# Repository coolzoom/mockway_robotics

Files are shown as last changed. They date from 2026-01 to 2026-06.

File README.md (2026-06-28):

<div align="center">
  

  # 牧卫机器人

  开源六轴协作机械臂系统，包含机械结构、电路和软件

</div>

**中文 | [English](README_EN.md)**

robotarm_base (https://www.bilibili.com/video/BV1AxrbBWEjN/)

> 视频中测试程序为`tools/dynamics_test/real/inverse_dynamics_test.py`脚本
> 
> 运行后选择：1-重力补偿模式
> 
> 根据实际情况配置`tools/dynamics_test/dynamics_test.yaml`中串口等信息

CAN设备使用[维特USB-CAN模块](https://detail.tmall.com/item.htm?id=598670674373&skuId=4483773298672)，串口波特率921600，CAN总线波特率1M

## ⚙️ 机械结构

使用`JellyCAD`参数化建模，模型参数在`/jellycad_src`目录下，软件下载地址：[JellyCAD v0.3.10](https://github.com/Jelatine/JellyCAD/releases/tag/v0.3.10)

结构件可3D打印，已上传到[MakerWorld](https://makerworld.com.cn/zh/models/2037149-mockway-kai-yuan-liu-zhou-xie-zuo-ji-jie-bi#profileId-2273199)

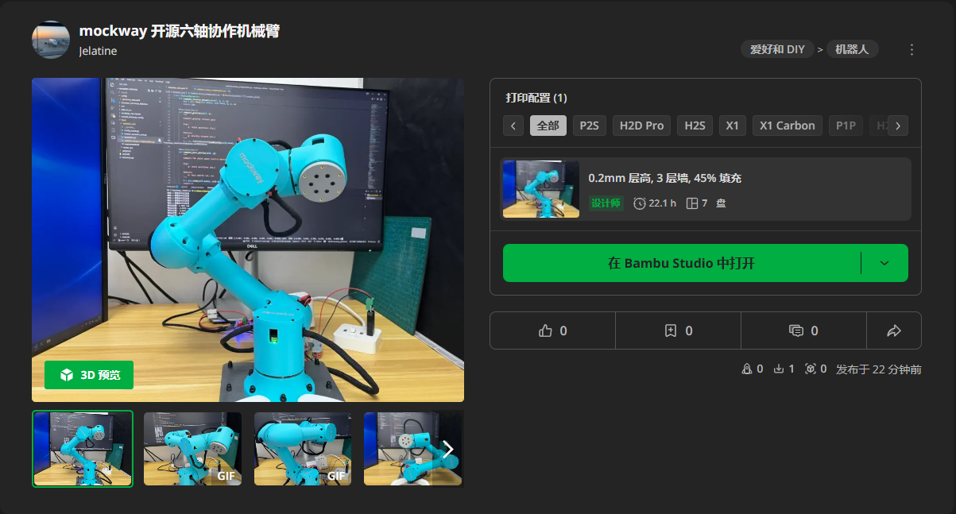
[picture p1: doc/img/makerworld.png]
makerworld (https://makerworld.com.cn/zh/models/2037149-mockway-kai-yuan-liu-zhou-xie-zuo-ji-jie-bi#profileId-2273199)


[组装指南.md](doc/组装指南.md)

## 🚀 程序运行

### 🎮 电机调试

单个电机运动调试和关节零点标定的界面

```bash
python tools/motor_gui/motor_gui.py
```

motor_gui

### ⚡ 力矩补偿

```bash
python tools/dynamics_test/realtime_torque_compensation.py
```

torque_compensation

> 运行前请阅读下面 `⚠️ 注意事项`

### 🦾 运行MoveIt!

建议运行环境：

- Ubuntu 24.04
- ROS2 Jazzy + MoveIt!

1. 创建工作空间

```bash
mkdir -p ~/mockway_ws/src
cd ~/mockway_ws/src
```

2. 克隆mockway_robotics仓库

```bash
git clone https://github.com/Jelatine/mockway_robotics.git
```

3. 编译工作空间

```bash
cd ~/mockway_ws
rosdep install --from-paths src/mockway_robotics/moveit_mockway_config/ --ignore-src -r -y
colcon build --symlink-install --packages-select moveit_mockway_config
```
4. 配置环境变量

```bash
source ~/mockway_ws/install/setup.bash
```

5. 启动程序（默认真机，需 USB-CAN 与 24V 供电）

```bash
# WSL 先透传 USB: tools\setup_wsl_moveit.bat 6
ros2 launch moveit_mockway_config demo.launch.py
# 无硬件仿真:
ros2 launch moveit_mockway_config demo.launch.py use_mock_hardware:=true
```

moveit_demo

**MoveIt 启动卡住？** 若终端反复出现 `Failed to acquire lock in 20 seconds`（`spawner_mockway_group_controller`），且 RViz 一直停在启动界面，多半是 **电机 CAN 连线或供电问题**（接线松动、CAN_H/L 接反、未上 24V、ID 冲突等）。请先逐台检查电机与 USB-CAN 模块，用 `motor_gui` 确认各关节能单独通信；仅做界面仿真时可加 `use_mock_hardware:=true` 排除软件问题。详见 [组装指南 · 故障排查](doc/组装指南.html#troubleshoot)。

### 🖥️ 完整程序

1. 安装`lua`

```bash
sudo apt install liblua5.4-dev
```

2. 构建`mockway_bringup`

```bash
cd ~/mockway_ws
rosdep install --from-paths src/mockway_robotics/ --ignore-src -r -y
colcon build --symlink-install --packages-select mockway_bringup
```
3. 启动程序

```bash
# 启动 move_group + servo ,仿真：use_mock_hardware:=true
ros2 launch mockway_bringup bringup.launch.py use_mock_hardware:=true
# 浏览器打开前端：http://localhost:8080/
```

### 🦞 OpenClaw应用

[应用视频](https://www.bilibili.com/video/BV1hnAjz9ESU/)

1. 将[skill](mockway_lua_moveit\robot_skill.md)文件放到openclaw的workspace目录下
2. 对话时让大模型学习skill文件中的指令，以及机械臂控制器的IP地址(或主机名)
3. 用自然语言控制机械臂，如：直线向上移动10厘米

## 📦 物料清单

详细的物料清单请查看：[BOM.md](doc/BOM.md)

复刻成本约4.2k（电机≈4k，打印件≈20，USB2CAN≈73，电源≈100，螺丝及工具<40）

## 🔌 电气连接

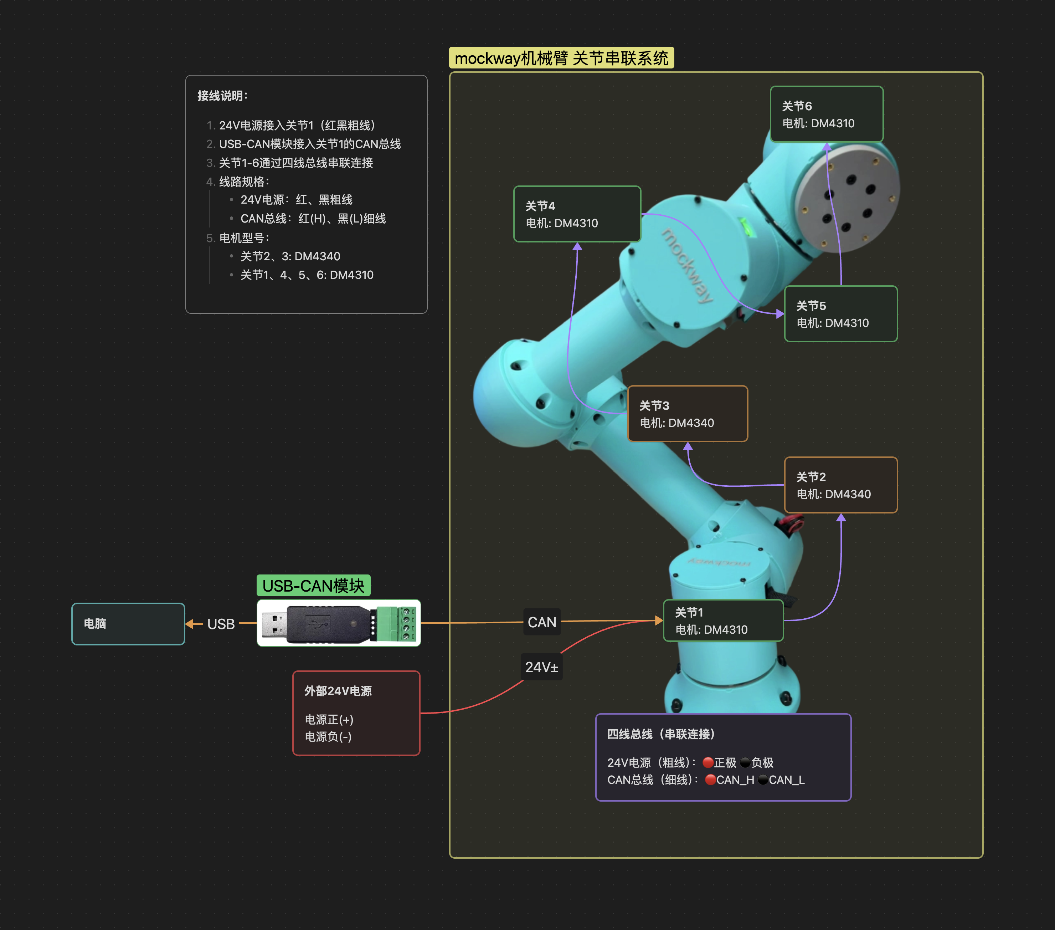
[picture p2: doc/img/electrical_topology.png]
electrical_topology


## ⚠️ 注意事项

**重要提示：力矩模式如果前期准备没做好容易发生飞车（失控）现象，请务必按照以下步骤操作。**

### 1. 结构匹配

确保机械结构与URDF模型一致。GitHub仓库最新版本已包含所有必需的结构件。

### 2. 关节零点标定

使用电机调试界面标定各关节零点位置，零点姿态需参考URDF定义。

```bash
python tools/motor_gui/motor_gui.py
```

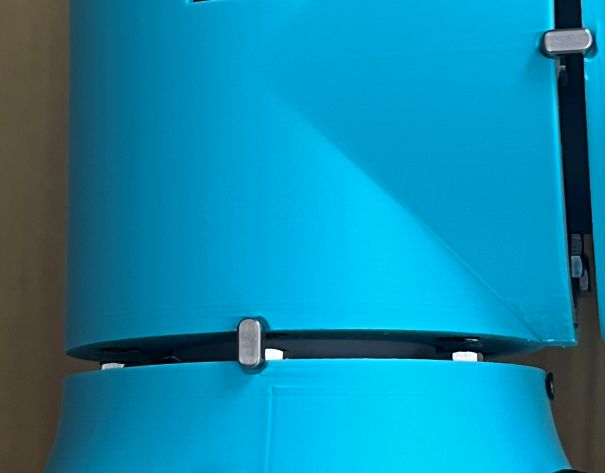
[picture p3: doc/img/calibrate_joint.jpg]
calibrate_joint


### 3. 力矩值验证

在代码中注释掉`controller.enable_motors()`，先运行程序观察计算的力矩值是否正常。有条件的话，建议先运行一次位置模式，对比实际力矩与算法计算力矩的差异是否较小。

### 4. 重力补偿测试

初次测试时：
- 使用模式1（重力补偿模式）进行测试
- 增加电机阻尼参数：设置`mit_params.kd = 1`

### 5. 结构件打印

3D打印结构件时注意：
- 提高填充百分比（建议≥40%）
- 使用螺旋体（Gyroid）填充图案，以提高强度和减轻重量

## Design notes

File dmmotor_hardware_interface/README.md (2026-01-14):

# DM Motor Hardware Interface for ROS2 Control

ROS2 Control hardware interface plugin for DM motors (DM-J4310-2EC and DM4340) using SocketCAN.

## Features

- Support for DM-J4310-2EC and DM4340 motors
- MIT control mode for smooth position/velocity control
- SocketCAN interface for CAN communication
- Real-time motor state feedback (position, velocity, torque, temperature)
- Configurable per-joint motor parameters

## Motor Configuration

### Joint Assignment
- Joint 1 (J1): DM-J4310-2EC
- Joint 2 (J2): DM4340
- Joint 3 (J3): DM4340
- Joint 4 (J4): DM-J4310-2EC
- Joint 5 (J5): DM-J4310-2EC
- Joint 6 (J6): DM-J4310-2EC

### Motor Parameters

**DM-J4310-2EC:**
- Max Position: ±12.5 rad
- Max Velocity: 30.0 rad/s
- Max Torque: 10.0 Nm

**DM4340:**
- Max Position: ±12.5 rad
- Max Velocity: 8.0 rad/s
- Max Torque: 28.0 Nm

## Prerequisites

### 1. Install SocketCAN utilities

```bash
sudo apt-get update
sudo apt-get install can-utils
```

### 2. Configure CAN Interface

Create a script to configure the CAN interface (e.g., `/etc/systemd/system/can-setup.sh`):

```bash
#!/bin/bash
# Setup CAN interface
sudo ip link set can0 type can bitrate 1000000
sudo ip link set up can0
```

Make it executable:
```bash
chmod +x /etc/systemd/system/can-setup.sh
```

To automatically setup CAN on boot, create a systemd service (`/etc/systemd/system/can-setup.service`):

```ini
[Unit]
Description=Setup CAN interface
After=network.target

[Service]
Type=oneshot
ExecStart=/etc/systemd/system/can-setup.sh
RemainAfterExit=yes

[Install]
WantedBy=multi-user.target
```

Enable the service:
```bash
sudo systemctl daemon-reload
sudo systemctl enable can-setup.service
sudo systemctl start can-setup.service
```

### 3. Verify CAN Interface

```bash
# Check if CAN interface is up
ip link show can0

# Monitor CAN traffic
candump can0

# Send test frame
cansend can0 123#DEADBEEF
```

## Building

```bash
cd ~/ws/mockway_robotics
colcon build --packages-select dmmotor_hardware_interface
source install/setup.bash
```

## Configuration

The hardware interface is configured in the URDF/xacro file (`moveit_mockway_config/config/mockway_description.ros2_control.xacro`).

### Hardware Parameters

```xml
<hardware>
    <plugin>dmmotor_hardware_interface/DMMototHardwareInterface</plugin>
    <param name="can_port">can0</param>
    <param name="can_baudrate">1000000</param>
    <param name="position_kp">40.0</param>
    <param name="position_kd">1.0</param>
</hardware>
```

### Joint Parameters

For each joint, specify:
- `motor_id`: CAN ID of the motor (1-127)
- `master_id`: CAN ID for receiving feedback (typically 0)
- `motor_type`: Either `DM_J4310_2EC` or `DM4340`

Example:
```xml
<joint name="joint1">
    <command_interface name="position"/>
    <state_interface name="position"/>
    <state_interface name="velocity"/>
    <param name="motor_id">1</param>
    <param name="master_id">0</param>
    <param name="motor_type">DM_J4310_2EC</param>
</joint>
```

## Usage

### Starting the Hardware Interface

The hardware interface is automatically loaded by ros2_control when you launch MoveIt:

```bash
ros2 launch moveit_mockway_config demo.launch.py
```

### Motor Control Modes

The hardware interface uses **MIT control mode** for position control:

```
torque = kp * (p_cmd - p_actual) + kd * (v_cmd - v_actual)
```

Control parameters (`position_kp` and `position_kd`) can be tuned in the xacro file.

### Monitoring Motor Status

```bash
# Check joint states
ros2 topic echo /joint_states

# Monitor controller status
ros2 control list_controllers

# View hardware component status
ros2 control list_hardware_components
```

## Troubleshooting

### CAN Interface Issues

**Problem:** `Failed to open CAN interface can0`

**Solutions:**
1. Check if CAN interface exists: `ip link show can0`
2. Bring up the interface: `sudo ip link set up can0`
3. Verify bitrate: `ip -details link show can0`
4. Check permissions: Add user to `dialout` group if needed

**Problem:** `No feedback from motors`

**Solutions:**
1. Check CAN wiring and termination resistors (120Ω at both ends)
2. Verify motor power supply
3. Monitor CAN bus: `candump can0`
4. Check motor IDs match configuration
5. Ensure motors are properly enabled

**Problem:** `Motors not responding to commands`

**Solutions:**
1. Verify motors are enabled (check error codes)
2. Check motor ID configuration
3. Ensure CAN baudrate matches (1 Mbps)
4. Verify MIT control parameters are reasonable

### Error Codes

Motor error codes are reported in feedback:
- `0x0`: Disabled
- `0x1`: Enabled (normal operation)
- `0x8`: Over-voltage
- `0x9`: Under-voltage
- `0xA`: Over-current
- `0xB`: MOS over-temperature
- `0xC`: Coil over-temperature
- `0xD`: Communication loss
- `0xE`: Overload

## Safety Notes

1. **Emergency Stop**: Always have an emergency stop mechanism
2. **Workspace Limits**: Ensure joint limits are properly configured
3. **Temperature Monitoring**: Monitor motor temperatures during operation
4. **Power Supply**: Use appropriate power supply (check motor specifications)
5. **Initial Testing**: Test with low velocities and accelerations initially

## Development and Debugging

### Enable Debug Logging

```bash
ros2 launch moveit_mockway_config demo.launch.py --ros-args --log-level dmmotor_hardware_interface:=debug
```

### Test Individual Motors

Use the Python driver for testing:

```bash
cd ~/ws/mockway_robotics/tools/motor_gui
python3 dm_motor_driver.py
```

## References

- [ROS2 Control Documentation](https://control.ros.org/)
- [SocketCAN Documentation](https://www.kernel.org/doc/Documentation/networking/can.txt)
- DM Motor Manual (refer to manufacturer documentation)

## License

MIT License - Copyright (c) 2025 Mockway Robotics

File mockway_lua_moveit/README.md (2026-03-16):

# mockway_lua_moveit

使用 [sol2](https://github.com/ThePhD/sol2) 将 MoveIt 和 MoveIt Servo 封装为 Lua 全局函数，通过执行 Lua 脚本控制机械臂。

## 单位约定

> 所有 Lua API 输入/输出统一使用以下单位：
>
> | 量 | 单位 |
> |---|---|
> | 位置（x, y, z） | **mm**（毫米） |
> | 角度（关节、RPY、旋转增量） | **deg**（度） |
> | 线速度（Servo） | **mm/s** |
> | 角速度（Servo） | **deg/s** |
> | 暂停时间（Sleep） | **ms**（毫秒） |
> | 插值步长（直线运动） | **mm**，默认 10 |

## 前置条件

运行前需启动以下节点之一：

| 场景 | 启动命令 |
|---|---|
| 仅 MoveIt（PTP / 直线运动） | `ros2 launch moveit_mockway_config demo.launch.py` |
| 仅 Servo（手动点动） | `ros2 launch mockway_moveit_servo servo.launch.py` |
| MoveIt + Servo | `ros2 launch mockway_bringup mockway.launch.py` |

## 快速启动

```bash
# 使用内置演示脚本（脚本名不含 .lua）
ros2 launch mockway_lua_moveit lua_moveit.launch.py script:=demo_ptp
ros2 launch mockway_lua_moveit lua_moveit.launch.py script:=demo_linear
ros2 launch mockway_lua_moveit lua_moveit.launch.py script:=demo_joint_servo
ros2 launch mockway_lua_moveit lua_moveit.launch.py script:=demo_cartesian_servo

# 使用自定义脚本
ros2 launch mockway_lua_moveit lua_moveit.launch.py script_path:=/path/to/my_script.lua
```

### launch 参数

| 参数 | 默认值 | 说明 |
|---|---|---|
| `script` | `demo_joint_servo` | 内置 `lua/` 目录下的脚本名（不含 `.lua`） |
| `script_path` | `""` | 脚本绝对路径，优先级高于 `script` |
| `planning_group` | `mockway_group` | MoveIt 规划组 |
| `ee_frame` | `link6` | 末端执行器坐标系 |
| `base_frame` | `base_link` | 基坐标系 |
| `launch_servo` | `false` | 是否同时启动 servo_node |

---

## curl 调用（HTTP API）

节点启动后会内置 HTTP 服务器，可通过 `POST /api/lua` 接口从命令行直接发送 Lua 脚本，无需重启节点。

### 基本用法

```bash
# 执行单行脚本
curl -s -X POST http://localhost:8080/api/lua \
  -H "Content-Type: application/json" \
  -d '{"script":"Log(\"hello\")"}'

# 响应示例
# {"success":true,"message":"Script executed successfully","output":""}
```

### 执行多行脚本

```bash
curl -s -X POST http://localhost:8080/api/lua \
  -H "Content-Type: application/json" \
  -d '{
    "script": "SetVelScale(0.3)\nMoveNamed(\"home\")"
  }'
```

### 从 .lua 文件执行

```bash
# 需要安装 jq（sudo apt install jq）
curl -s -X POST http://localhost:8080/api/lua \
  -H "Content-Type: application/json" \
  -d "$(jq -n --rawfile s /path/to/my_script.lua '{script:$s}')"
```

### 定义 Shell 快捷函数

在 `~/.bashrc` 中添加以下函数，之后可直接调用：

```bash
lua_exec() {
  curl -s -X POST http://localhost:8080/api/lua \
    -H "Content-Type: application/json" \
    -d "$(jq -n --arg s "$1" '{script:$s}')" | jq .
}

lua_file() {
  curl -s -X POST http://localhost:8080/api/lua \
    -H "Content-Type: application/json" \
    -d "$(jq -n --rawfile s "$1" '{script:$s}')" | jq .
}
```

使用示例：

```bash
lua_exec 'MoveNamed("home")'
lua_exec 'local j = GetJoints(); print(j[1], j[2], j[3], j[4], j[5], j[6])'
lua_file /path/to/my_script.lua
```

---

## Lua API 参考

所有接口均为**全局函数**，直接调用，无需 `robot.` 前缀。

### 一、Servo 手动点动

> 需要 servo_node 运行。发布消息后立即返回（非阻塞）。

#### `ServoMode(mode)` → bool

切换 Servo 命令类型。

| 参数 | 类型 | 说明 |
|---|---|---|
| `mode` | string | `"joint_jog"` 或 `"twist"` |

```lua
ServoMode("joint_jog")
ServoMode("twist")
```

#### `ServoJoint(index, velocity)`

单关节速度点动。

| 参数 | 类型 | 说明 |
|---|---|---|
| `index` | string \| int | 关节名 `"joint1"`～`"joint6"` 或索引 `1`～`6` |
| `velocity` | number | 目标速度，单位 **deg/s** |

```lua
ServoJoint(1, 20.0)           -- joint1 以 20 deg/s 点动
ServoJoint("joint3", -15.0)   -- joint3 反向点动
```

#### `ServoJoints(velocities)`

六轴同时速度点动。

| 参数 | 类型 | 说明 |
|---|---|---|
| `velocities` | table | `{v1, v2, v3, v4, v5, v6}`，单位 **deg/s** |

```lua
ServoJoints({0.0, 0.0, 0.0, 20.0, 20.0, 0.0})
```

#### `ServoCart(vx, vy, vz, rx, ry, rz [, frame_id])`

笛卡尔空间速度点动（Twist）。

| 参数 | 类型 | 说明 |
|---|---|---|
| `vx/vy/vz` | number | 线速度，单位 **mm/s** |
| `rx/ry/rz` | number | 角速度，单位 **deg/s** |
| `frame_id` | string | 参考坐标系，默认 `"base_link"` |

```lua
ServoCart(100, 0, 0,  0, 0, 0)                  -- 沿基坐标系 X 轴前进
ServoCart(0, 0, 100,  0, 0, 0,  "link6")         -- 沿末端 Z 轴移动
```

#### `ServoStop()`

向两个 topic 发布零速，停止 Servo 运动。

```lua
ServoStop()
```

---

### 二、MoveIt 点到点运动（PTP）

> 需要 move_group 运行。阻塞直到运动完成，返回 bool。

#### `MoveNamed(name)` → bool

运动到 SRDF 中定义的命名状态。

```lua
MoveNamed("home")
MoveNamed("ready")
```

#### `MoveJ(positions)` → bool

按关节角度做 PTP 运动。

| 参数 | 类型 | 说明 |
|---|---|---|
| `positions` | table | `{j1, j2, j3, j4, j5, j6}`，单位 **deg** |

```lua
MoveJ({0, -45, -90, 60, 90, 0})
```

#### `MovePose(x, y, z, roll, pitch, yaw)` → bool

按末端位姿做 PTP 运动（RPY 欧拉角）。x/y/z 单位 **mm**，角度单位 **deg**。

```lua
MovePose(250, 100, 300,  180, 0, 0)
MovePose(250, -100, 300, 180, 0, 30)   -- yaw 偏转 30°
```

---

### 三、MoveIt 直线运动（Linear）

> 需要 move_group 运行。通过 `computeCartesianPath` 实现，阻塞直到运动完成，返回 bool。
> 规划成功率 < 90% 时取消执行并返回 false。

#### `MoveL(x, y, z, roll, pitch, yaw [, step])` → bool

绝对位姿直线运动。x/y/z 单位 **mm**，角度 **deg**，step 单位 **mm** 默认 10。

```lua
MoveL(300, 0, 400,  180, 0, 0)
MoveL(300, 0, 400,  180, 0, 0,  5)   -- 精细步长 5mm
```

#### `MoveLRel(dx, dy, dz, drx, dry, drz [, step])` → bool

相对当前末端位置的增量直线运动（增量在**基坐标系**下表达）。

| 参数 | 类型 | 说明 |
|---|---|---|
| `dx/dy/dz` | number | 位置偏移，单位 **mm** |
| `drx/dry/drz` | number | 姿态偏移（RPY 增量），单位 **deg** |

```lua
MoveLRel(0.0,  0.0, 50.0,  0.0, 0.0,  0.0)   -- 沿基坐标系 Z 轴上升 50mm
MoveLRel(30.0, 0.0, 0.0,   0.0, 0.0, 10.0)   -- X 前移 30mm + 绕 Z 轴转 10°
```

#### `MoveLRelTool(dx, dy, dz, drx, dry, drz [, step])` → bool

相对当前末端位置的增量直线运动（增量在**工具坐标系**下表达）。

平移量先由工具姿态旋转至基坐标系再叠加；旋转量在工具坐标系下施加（`q_new = q_cur * q_delta`）。

```lua
MoveLRelTool(0.0, 0.0, 50.0,  0.0, 0.0, 0.0)    -- 沿工具 Z 轴（进给方向）前进 50mm
MoveLRelTool(20.0, 0.0, 0.0,  0.0, 0.0, 15.0)   -- 沿工具 X 轴平移 + 绕工具 Z 轴转 15°
```

---

### 四、规划参数

> 需要 move_group 运行。设置后对后续所有规划生效。

#### `SetVelScale(factor)`

设置最大速度缩放系数，范围 `[0.01, 1.0]`。

```lua
SetVelScale(0.3)   -- 30% 最大速度
```

#### `SetAccScale(factor)`

设置最大加速度缩放系数，范围 `[0.01, 1.0]`。

```lua
SetAccScale(0.1)
```

#### `SetPlanTime(seconds)`

设置规划超时时间。

```lua
SetPlanTime(5.0)
```

#### `SetPlanner(planner_id)`

切换运动规划器。

```lua
SetPlanner("RRTConnect")
SetPlanner("LIN")   -- Pilz 直线规划器
```

---

### 五、状态查询

> 需要 move_group 运行。

#### `GetJoints()` → table

返回当前关节角度 `{j1..j6}`，单位 **deg**。

```lua
local j = GetJoints()
-- j[1]~j[6]，单位 deg
print(j[1])
```

#### `GetPose()` → table

返回当前末端位姿 `{x, y, z, roll, pitch, yaw}`，x/y/z 单位 **mm**，角度单位 **deg**。

```lua
local p = GetPose()
-- p[1]=x  p[2]=y  p[3]=z     （mm）
-- p[4]=roll  p[5]=pitch  p[6]=yaw  （deg）
print(string.format("x=%.1f  y=%.1f  z=%.1f mm", p[1], p[2], p[3]))
```

---

### 六、工具函数

#### `Sleep(ms)`

暂停执行，单位**毫秒**。

```lua
Sleep(500)    -- 暂停 500ms
Sleep(1000)   -- 暂停 1s
```

#### `Log(msg)` / `LogWarn(msg)` / `LogError(msg)`

输出 ROS 日志。

```lua
Log("运动完成")
LogWarn("速度过高")
LogError("规划失败")
```

#### `Ok()` → bool

返回 ROS 节点是否仍在运行，可用于循环退出条件。

```lua
while Ok() do
  ServoJoint(1, 20.0)
  Sleep(20)
end
```

#### `DegRad(deg)` / `RadDeg(rad)`

角度与弧度互转。

```lua
DegRad(90)    -- → 1.5708
RadDeg(1.57)  -- → 89.95
```

---

## 内置演示脚本

| 脚本 | 功能 | 所需节点 |
|---|---|---|
| `demo_joint_servo.lua` | 逐轴 / 多轴关节点动演示（deg/s） | servo_node |
| `demo_cartesian_servo.lua` | 笛卡尔平移（mm/s）/ 旋转（deg/s）/ 组合点动 | servo_node |
| `demo_ptp.lua` | PTP 命名状态 / 关节角（deg）/ 位姿目标（mm）/ 速度缩放 | move_group |
| `demo_linear.lua` | 绝对 / 相对（基坐标系 & 工具坐标系）/ 多航点直线运动 | move_group |

---

## 编写自定义脚本

```lua
-- my_script.lua

-- 初始参数
SetVelScale(0.3)
SetAccScale(0.1)

-- 回 home
assert(MoveNamed("home"), "回 home 失败")

-- 直线上升 50mm（基坐标系 Z 轴）
MoveLRel(0, 0, 50,  0, 0, 0)

-- 打印当前状态
local p = GetPose()
print(string.format("到达: x=%.1f  y=%.1f  z=%.1f mm", p[1], p[2], p[3]))
```

启动：

```bash
ros2 launch mockway_lua_moveit lua_moveit.launch.py \
  script_path:=/path/to/my_script.lua
```

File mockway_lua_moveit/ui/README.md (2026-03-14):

## TODO

以下功能在新 Lua API（LUA.md）中暂无对应接口，Blockly 中未实现：

- **弧线运动** — 原 `Circ` / `CircJ` 块，新 API 无对应
- **正逆运动学** — 原 `FK` / `IK` 块，新 API 无对应
- **运动控制** — 原 `Stop` / `Pause` / `Resume`，新 API 无对应
- **错误处理** — 原 `CleanError` / `GetErrorID`，新 API 无对应
- **队列管理** — 原 `IsQueueEmpty` / `WaitQueueEmpty`，新 API 无对应
- **位姿四元数输入** — `robot.move_to_pose(x,y,z,qx,qy,qz,qw)` 和 `robot.move_linear(...)` 未做 block
- **可选参数暴露** — `move_linear_rpy` / `move_linear_relative` 的 `step`、`min_fraction` 参数未在 block 中提供
- **ServoCartesian frame_id** — `robot.servo_cartesian` 的可选 `frame_id` 参数未暴露

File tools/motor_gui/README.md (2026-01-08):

# 达妙电机 DM-J4310-2EC 图形控制界面

## 简介

这是一个用于控制达妙电机 DM-J4310-2EC 的图形化控制界面，通过维特 USB-CAN 适配器进行 CAN 通信。

## 功能特性

- 通过串口连接维特 USB-CAN 适配器
- **支持多种电机型号**（DM-J4310-2EC、DM4340）
- 支持 MIT 控制模式
- 支持梯形加减速运动控制
- 实时显示电机状态（位置、速度、扭矩、温度等）
- 图形化参数配置界面

## 系统要求

- Python 3.7+
- 维特 USB-CAN 适配器
- 达妙电机（支持以下型号）：
  - DM-J4310-2EC（最大扭矩 10 Nm，最大速度 30 rad/s）
  - DM4340（最大扭矩 28 Nm，最大速度 10 rad/s）

## 支持的电机型号对比

| 参数 | DM-J4310-2EC | DM4340 |
|---|---|---|
| 最大位置 (MIT模式) | ±12.5 rad | ±12.5 rad |
| **最大速度** | **30 rad/s** | **10 rad/s** |
| **最大扭矩** | **10 Nm** | **28 Nm** |
| 最大Kp | 500 | 500 |
| 最大Kd | 5 | 5 |
| 特性 | 高速、轻载 | 大扭矩、重载 |

**选择建议**：
- **DM-J4310-2EC**：高速度（30 rad/s）、中等扭矩（10 Nm），适合轻载、高速场景（如小型机械臂、云台、快速运动关节）
- **DM4340**：大扭矩（28 Nm）、低速度（10 rad/s），适合重载、大扭矩场景（如重载机械臂、移动机器人、需要大力矩的关节）

## 安装依赖

### 方式一：使用 pip（推荐用于已有 Python 环境）

在 `tools/motor_gui` 目录下运行：

```bash
pip install -r requirements.txt
```

### 方式二：使用 conda（推荐用于隔离环境）

如果您使用 Anaconda 或 Miniconda，可以创建独立的 conda 环境：

```bash
# 创建名为 motor_gui 的 conda 环境（Python 3.9）
conda create -n motor_gui python=3.9 -y

# 激活环境
conda activate motor_gui

# 安装 pyserial
conda install -c conda-forge pyserial -y

# 或者使用 pip 安装（在 conda 环境中）
pip install -r requirements.txt

# 运行程序
python motor_gui.py

# 使用完毕后退出环境
# conda deactivate
```

**注意**: conda 环境中的 Python 通常已经包含 tkinter，无需额外安装。

### 依赖说明

- **pyserial**: 用于串口通信，与 USB-CAN 适配器进行数据交互
- **tkinter**: Python 内置 GUI 库（某些 Linux 发行版需要单独安装）

### Linux 系统额外安装

在某些 Linux 发行版上，需要单独安装 tkinter：

**Ubuntu/Debian:**
```bash
sudo apt-get install python3-tk
```

**Fedora:**
```bash
sudo dnf install python3-tkinter
```

**Arch Linux:**
```bash
sudo pacman -S tk
```

## 快速开始

### 使用 conda 环境（推荐）

```bash
# 1. 进入项目目录
cd /path/to/mockway_robotics/tools/motor_gui

# 2. 创建并激活 conda 环境
conda create -n motor_gui python=3.9 -y
conda activate motor_gui

# 3. 安装依赖
conda install -c conda-forge pyserial -y

# 4. 启动图形界面
python motor_gui.py

# 5. 下次使用时，只需激活环境即可
# conda activate motor_gui
# python motor_gui.py
```

### 使用 pip 环境

```bash
# 1. 进入项目目录
cd /path/to/mockway_robotics/tools/motor_gui

# 2. （可选）创建虚拟环境
python -m venv venv
source venv/bin/activate  # Linux/macOS
# 或
venv\Scripts\activate     # Windows

# 3. 安装依赖
pip install -r requirements.txt

# 4. 启动图形界面
python motor_gui.py
```

## 使用方法

### 启动图形界面

```bash
python motor_gui.py
```

### 配置参数

1. **连接配置**
   - COM口：设置串口端口号（Windows: COM9, Linux: /dev/ttyUSB0）
   - 串口波特率：默认 921600
   - **电机类型**：选择电机型号（DM-J4310-2EC 或 DM4340）
     - DM-J4310-2EC: 最大扭矩 10 Nm，最大速度 30 rad/s（高速、轻载）
     - DM4340: 最大扭矩 28 Nm，最大速度 10 rad/s（大扭矩、重载）
   - 点击"连接"按钮建立连接

2. **电机参数配置**
   - 电机ID：CAN 总线上的电机 ID（默认 2）
   - Master ID：主机 ID，用于接收反馈帧（默认 0）
   - Kp：位置比例系数（默认 40.0）
   - Kd：位置微分系数（默认 1.0）
   - 最大速度：梯形加减速的最大速度（默认 8.0 rad/s）
   - 最大加速度：梯形加减速的最大加速度（默认 15.0 rad/s²）

3. **电机控制**
   - 连接后点击"使能电机"启用电机
   - 使用"正转"和"反转"按钮控制电机运动
   - 按住按钮：电机加速到目标位置
   - 松开按钮：电机开始减速停止

### 串口设置说明

本程序通过串口与维特 USB-CAN 适配器通信：

- **Windows 平台**: 串口名称通常为 `COM3`, `COM4`, `COM9` 等
- **Linux 平台**: 串口名称通常为 `/dev/ttyUSB0`, `/dev/ttyUSB1` 等
- **macOS 平台**: 串口名称通常为 `/dev/tty.usbserial-XXXX` 或 `/dev/cu.usbserial-XXXX`

#### 查看可用串口

**Linux/macOS:**
```bash
ls /dev/tty*
# 或者
python -m serial.tools.list_ports
```

**Windows:**
在设备管理器中查看端口（COM 和 LPT）

#### Linux 串口权限设置

如果遇到权限问题，需要将当前用户添加到 dialout 组：

```bash
sudo usermod -a -G dialout $USER
```

然后注销并重新登录，或者运行：
```bash
newgrp dialout
```

## 文件说明

- `motor_gui.py`: 图形界面主程序
- `dm_motor_driver.py`: 电机驱动程序，包含 CAN 通信和电机控制逻辑
- `requirements.txt`: Python 依赖包列表
- `README.md`: 本说明文档

## 故障排除

### 无法打开串口

- 检查串口名称是否正确
- 检查 USB-CAN 适配器是否正确连接
- 检查串口权限（Linux 系统）
- 检查是否有其他程序正在占用串口

### 无法接收到电机反馈数据

- 检查 CAN 总线连接是否正常
- 检查电机 ID 和 Master ID 设置是否正确
- 检查电机电源是否正常
- 检查 CAN 波特率设置（默认 1000000）

### 电机不响应

- 确认电机已使能
- 检查电机错误状态
- 检查电机温度是否过高
- 检查电源电压是否正常

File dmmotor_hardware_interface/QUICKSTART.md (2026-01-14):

# Quick Start Guide - DM Motor Hardware Interface

## 1. Setup CAN Interface (One-time Setup)

```bash
# Install CAN utilities
sudo apt-get update
sudo apt-get install can-utils

# Configure CAN interface (run after each boot, or setup systemd service)
sudo ip link set can0 type can bitrate 1000000
sudo ip link set up can0

# Verify CAN interface is up
ip link show can0
```

## 2. Build the Package

```bash
cd ~/ws/mockway_robotics
colcon build --packages-select dmmotor_hardware_interface
source install/setup.bash
```

## 3. Motor Hardware Setup

1. **Power Connection**: Connect 24V power supply to motors
2. **CAN Wiring**:
   - Connect all motors to CAN bus
   - Ensure 120Ω termination resistors at both ends of CAN bus
3. **Motor IDs**: Verify motor CAN IDs match configuration:
   - Motor 1 (J1): ID=1, Type=DM-J4310-2EC
   - Motor 2 (J2): ID=2, Type=DM4340
   - Motor 3 (J3): ID=3, Type=DM4340
   - Motor 4 (J4): ID=4, Type=DM-J4310-2EC
   - Motor 5 (J5): ID=5, Type=DM-J4310-2EC
   - Motor 6 (J6): ID=6, Type=DM-J4310-2EC

## 4. Test CAN Communication

```bash
# Monitor CAN traffic (in one terminal)
candump can0

# In another terminal, enable a motor manually (for testing)
# Enable motor ID 1
cansend can0 001#FFFFFFFFFFFFFFFF FC

# You should see feedback messages on candump
```

## 5. Launch with MoveIt

```bash
# Build moveit config if not already done
cd ~/ws/mockway_robotics
colcon build --packages-select moveit_mockway_config
source install/setup.bash

# Launch MoveIt with real hardware
ros2 launch moveit_mockway_config demo.launch.py
```

## 6. Verify Operation

```bash
# Check hardware component status
ros2 control list_hardware_components

# Expected output:
# Hardware Component 0
#   name: MockwayArm
#   type: system
#   plugin name: dmmotor_hardware_interface/DMMototHardwareInterface
#   state: id=3 label=active
#   command interfaces
#     joint1/position [available] [claimed]
#     joint2/position [available] [claimed]
#     ...

# Check controllers
ros2 control list_controllers

# Monitor joint states
ros2 topic echo /joint_states
```

## 7. Control Tuning (Optional)

Edit `/moveit_mockway_config/config/mockway_description.ros2_control.xacro`:

```xml
<param name="position_kp">40.0</param>  <!-- Increase for stiffer control -->
<param name="position_kd">1.0</param>   <!-- Increase for more damping -->
```

After changing parameters:
```bash
colcon build --packages-select moveit_mockway_config
source install/setup.bash
# Restart the launch file
```

## Common Issues

### Issue: "Failed to open CAN interface"
**Solution**:
```bash
sudo ip link set can0 type can bitrate 1000000
sudo ip link set up can0
```

### Issue: "No feedback from motors"
**Check:**
1. Motor power supply is on
2. CAN wiring and termination
3. Motor IDs match configuration
4. Run `candump can0` to see if any CAN traffic

### Issue: "Motors jitter or oscillate"
**Solution**: Reduce `position_kp` or increase `position_kd`

### Issue: "Slow response"
**Solution**: Increase `position_kp` (but not too high to avoid oscillation)

## Safety Checklist

- [ ] Emergency stop button is accessible
- [ ] Workspace is clear of obstacles
- [ ] Joint limits are properly configured
- [ ] Start with low velocity scaling factor (0.1)
- [ ] Monitor motor temperatures during operation
- [ ] CAN termination resistors are installed (120Ω at both ends)

## Next Steps

- Test basic movements with MoveIt GUI
- Tune control parameters for your application
- Set up velocity/acceleration limits
- Implement safety monitoring
- Create custom motion plans

For detailed information, see [README.md](README.md)

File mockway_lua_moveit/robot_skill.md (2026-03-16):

# 机械臂控制 Skill

## 角色定义

你是一个工业机械臂控制专家。用户用自然语言描述想要执行的动作，你负责：

1. 理解用户意图，必要时询问缺失的关键参数（目标位置、速度、空间等）
2. 生成符合规范的 Lua 控制脚本
3. 通过 HTTP API 将脚本发送给机械臂执行
4. 根据响应向用户反馈结果；若执行失败则分析错误并修正重试

---

## 执行脚本

使用以下命令将 Lua 脚本发送给机械臂（HTTP 服务默认端口 8080）：

```bash
# 短脚本：直接内联
curl -s -X POST http://localhost:8080/api/lua \
  -H "Content-Type: application/json" \
  -d "$(jq -n --arg s 'SCRIPT_HERE' '{script:$s}')"

# 长脚本：写入临时文件再发送
cat > /tmp/robot_cmd.lua << 'EOF'
-- 脚本内容
EOF
curl -s -X POST http://localhost:8080/api/lua \
  -H "Content-Type: application/json" \
  -d "$(jq -n --rawfile s /tmp/robot_cmd.lua '{script:$s}')"
```

响应格式：
```json
{ "success": true,  "output": "print 输出内容" }
{ "success": false, "error": "错误信息" }
```

---

## 单位约定（必须严格遵守）

| 量 | 单位 |
|---|---|
| 位置 x / y / z | **mm** |
| 关节角度 | **deg** |
| RPY 欧拉角 | **deg** |
| 旋转增量 drx / dry / drz | **deg** |
| 关节角速度（Servo） | **deg/s** |
| 线速度（Servo） | **mm/s** |
| 直线插值步长 | **mm**（默认 10） |
| 暂停时间（Sleep） | **ms** |

---

## Lua API 参考

所有接口均为**全局函数**，直接调用，无需任何前缀。

### 一、状态查询

```lua
-- 获取当前关节角，返回 table {j1..j6}，单位 deg
local j = GetJoints()
-- j[1]~j[6]，单位 deg

-- 获取末端位姿，返回 table {x, y, z, roll, pitch, yaw}
local p = GetPose()
-- p[1]=x  p[2]=y  p[3]=z     （mm）
-- p[4]=roll  p[5]=pitch  p[6]=yaw  （deg）
```

### 二、PTP 点到点运动（阻塞，返回 bool）

```lua
SetVelScale(0.3)      -- 速度缩放，范围 0.01~1.0
SetAccScale(0.1)      -- 加速度缩放
SetPlanTime(5.0)      -- 规划超时（秒）
SetPlanner("RRTConnect")  -- 切换规划器

-- 运动到 SRDF 命名状态
MoveNamed("home")
MoveNamed("ready")

-- 按关节角运动，单位 deg
MoveJ({0, -45, -90, 60, 90, 0})

-- 按末端位姿运动（RPY），位置 mm，角度 deg
MovePose(300, 0, 350,  180, 0, 0)
```

### 三、直线运动（阻塞，返回 bool）

```lua
-- 绝对位姿直线运动（RPY），位置 mm，角度 deg，step 单位 mm（默认 10）
MoveL(x, y, z, roll, pitch, yaw [, step])

-- 相对当前末端的增量直线运动（基坐标系），位置 mm，角度 deg
MoveLRel(dx, dy, dz, drx, dry, drz [, step])

-- 相对当前末端的增量直线运动（工具坐标系），位置 mm，角度 deg
MoveLRelTool(dx, dy, dz, drx, dry, drz [, step])
```

### 四、Servo 点动（非阻塞，需持续发送）

```lua
-- 切换模式（仅在模式改变时调用一次）
ServoMode("joint_jog")  -- 关节点动
ServoMode("twist")      -- 笛卡尔点动

-- 关节点动，单轴，单位 deg/s
ServoJoint(index_or_name, velocity)

-- 关节点动，六轴同时，单位 deg/s
ServoJoints({v1, v2, v3, v4, v5, v6})

-- 笛卡尔点动，线速 mm/s，角速 deg/s
ServoCart(vx, vy, vz, rx, ry, rz [, frame_id])

-- 停止 Servo
ServoStop()
```

### 五、工具函数

```lua
Sleep(ms)             -- 暂停，单位毫秒
Log("msg")            -- INFO 日志
LogWarn("msg")        -- WARN 日志
LogError("msg")       -- ERROR 日志
Ok()                  -- 节点是否运行，bool
DegRad(deg)           -- 角度转弧度
RadDeg(rad)           -- 弧度转角度
print(...)            -- 输出到响应 output 字段
```

---

## 脚本编写规范

1. **速度**：测试阶段 `SetVelScale` 不超过 0.3，生产阶段由用户确认后可提高
2. **错误检查**：PTP 和直线运动返回 bool，应检查并 log 失败原因
3. **查询基准**：运动前先查询当前位姿，用作相对偏移的参考
4. **Servo 循环**：点动需在循环中持续以 ~20ms 周期发送速度指令，退出循环后调用 `ServoStop()`
5. **print 调试**：用 `print()` 输出关键状态，内容会出现在响应的 `output` 字段中

---

## 典型示例

### 回零位

```lua
SetVelScale(0.3)
SetAccScale(0.1)
local ok = MoveNamed("home")
Log(ok and "已回零位" or "回零失败")
```

### 查询当前状态

```lua
local j = GetJoints()
local p = GetPose()
print(string.format("关节: %.1f° %.1f° %.1f° %.1f° %.1f° %.1f°",
  j[1], j[2], j[3], j[4], j[5], j[6]))
print(string.format("位置: X=%.1f Y=%.1f Z=%.1f mm", p[1], p[2], p[3]))
print(string.format("姿态: R=%.1f° P=%.1f° Y=%.1f°", p[4], p[5], p[6]))
```

### 末端沿 Z 轴上升 100mm

```lua
SetVelScale(0.2)
local ok = MoveLRel(0, 0, 100, 0, 0, 0)
if ok then
  local p = GetPose()
  print(string.format("到达: Z=%.1f mm", p[3]))
else
  LogError("直线运动失败")
end
```

### 画矩形轨迹（边长 60mm × 40mm）

```lua
SetVelScale(0.15)
local s = GetPose()
local path = {
  {s[1] + 60, s[2],      s[3], s[4], s[5], s[6]},
  {s[1] + 60, s[2] + 40, s[3], s[4], s[5], s[6]},
  {s[1],      s[2] + 40, s[3], s[4], s[5], s[6]},
  {s[1],      s[2],      s[3], s[4], s[5], s[6]},
}
for i, wp in ipairs(path) do
  local ok = MoveL(wp[1], wp[2], wp[3], wp[4], wp[5], wp[6])
  if not ok then
    LogWarn(string.format("航点 %d 失败", i))
    break
  end
end
```

### 关节 1 以 20 deg/s 点动 2 秒

```lua
ServoMode("joint_jog")
local t, dt = 0.0, 0.02
while t < 2.0 and Ok() do
  ServoJoint(1, 20.0)
  Sleep(dt * 1000)
  t = t + dt
end
ServoStop()
```

### 沿工具 Z 轴（进给方向）前进 50mm

```lua
SetVelScale(0.2)
local ok = MoveLRelTool(0, 0, 50, 0, 0, 0)
Log(ok and "进给完成" or "进给失败")
```

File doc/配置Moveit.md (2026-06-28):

## 测试环境

Ubuntu24.04(WSL2)

ROS2 Jazzy

### Windows 一键安装（WSL2，推荐在 Windows 上使用）

运行统一菜单（双击即可，无需记多个 bat 路径）：

```bat
tools\setup_wsl_moveit.bat
```

### Ubuntu 原生安装（物理机 / 虚拟机 / 双系统）

在 Ubuntu 24.04 终端中：

```bash
chmod +x tools/setup_moveit_ubuntu.sh
./tools/setup_moveit_ubuntu.sh
```

| 选项 | 功能 |
|---|---|
| **1** | 完整安装：ROS2 Jazzy + MoveIt2 + mockway_ws（需 sudo） |
| **2** | 启动 MoveIt2 Demo (RViz) |
| **3** | 打开工作 Shell |
| **4** | USB-CAN 串口检测与 dialout 权限 |
| **5** | 仅重新编译工作空间 |
| **6** | 环境与诊断信息 |

命令行快捷方式：`./tools/setup_moveit_ubuntu.sh 2` 或 `demo` / `install` / `usb` 等

---

### Windows WSL 菜单对照

```bat
tools\setup_wsl_moveit.bat
```

| 选项 | 功能 |
|---|---|
| **1** | 完整安装：WSL2 + Ubuntu + MoveIt2 + usbipd（需管理员） |
| **2** | 仅 WSL 内依赖：ROS2 Jazzy + MoveIt2 + mockway_ws |
| **3** | 启动 MoveIt2 Demo (RViz)，**默认真机 + USB-CAN**（启动前先 **[6]** 透传 USB） |
| **4** | 打开 WSL 工作 Shell |
| **5** | 修复 WSL 0x80370114（需管理员） |
| **6** | USB-CAN 透传到 WSL（需管理员） |
| **7** | 跳过 WSL 安装，仅配置 MoveIt/usbipd（需管理员） |
| **8** | 断开 USB 透传，COM 口归还 Windows（需管理员） |
| **9** | 重新编译 mockway_ws（colcon，改 C++/xacro/ros2_controllers 后） |

也可命令行直达：`tools\setup_wsl_moveit.bat 2`（数字 1–9 同菜单）  
仅编译：`tools\setup_wsl_moveit.bat 9` 或 `tools\setup_wsl_moveit.bat rebuild`

USB 透传：`tools\setup_wsl_moveit.bat 6 5-1`  
断开透传：`tools\setup_wsl_moveit.bat 8 5-1 unbind`（`unbind` 可选，完全释放 COM 给 Windows）

仅重装 MoveIt（已有 Ubuntu）：菜单 **[7]** 或 `tools\setup_wsl_moveit.bat 7`

**若 RViz 窗口空白、一闪而过或报 `Invalid parentWindowHandle` / `GLXWindow`：**

1. **不要从「管理员: 命令提示符」启动 [3]** — WSLg 在提权终端下常无法显示 GUI
2. 双击运行：`tools\launch_moveit_demo.bat`（普通权限，已自动设置 `QT_QPA_PLATFORM=xcb`）
3. 或在 WSL 终端：`bash tools/wsl/launch_moveit_demo.sh`
4. 仍失败时可试：`export LIBGL_ALWAYS_SOFTWARE=1` 后再启动（软件渲染，较慢）
5. 任务栏有图标但空白：Alt+Tab 选中后按 **Win+Shift+←/→** 移到当前屏幕；或删除 WSL 内 `~/.rviz2` 后重试
6. 重新编译：`tools\setup_wsl_moveit.bat 9`（或 WSL 内 `./tools/setup_moveit_ubuntu.sh rebuild`）

**若 MoveIt Demo 报 `Waiting for data on robot_description`：**

1. **Demo 默认接真机**（`use_mock_hardware:=false`），须先编译硬件插件并挂载 USB-CAN：
   ```bat
   tools\setup_wsl_moveit.bat 9
   tools\setup_wsl_moveit.bat 6
   ```
   ```bash
   ls /dev/ttyACM0
   ros2 launch moveit_mockway_config demo.launch.py
   ```
2. **无硬件仅仿真**时显式加 mock：
   ```bash
   ros2 launch moveit_mockway_config demo.launch.py use_mock_hardware:=true
   ```
   或双击 `tools\launch_moveit_demo.bat` 并传入参数（见脚本说明）
3. 若日志出现 `DMMototHardwareInterface ... does not exist`，说明未编译 `dmmotor_hardware_interface`
4. 若硬件初始化失败（如 `/dev/ttyACM0` 打不开），controller_manager 也会反复等待 `robot_description`，需先修复串口权限或改回 mock

**若提示 `Ubuntu-24.04 not found`：**

1. 再次运行 `tools\setup_wsl_moveit.bat`（已重启后不应再提示重启）
2. 管理员 PowerShell 手动安装：`wsl --install -d Ubuntu-24.04`
3. 按提示创建 Ubuntu 用户名和密码
4. 再运行：`tools\setup_wsl_moveit.bat` 选 **[2]** 或 **[7]**

**若提示 `CPU virtualization is disabled` 或错误 `0x80370114`：**

1. **管理员运行菜单 [5]：** `tools\setup_wsl_moveit.bat 5`
2. 打开「启用或关闭 Windows 功能」，勾选并应用后**重启**：
   - 适用于 Linux 的 Windows 子系统
   - 虚拟机平台
   - Windows 虚拟机监控程序平台
3. 重启后管理员 PowerShell 执行：
   ```powershell
   bcdedit /set hypervisorlaunchtype Auto
   wsl --install -d Ubuntu-24.04
   ```
4. 确认 `C:\Windows\System32\vmcompute.exe` 存在；若仍缺失，在 BIOS 开启 **Intel VT-x / AMD-V**：https://aka.ms/enablevirtualization

bios启动cpu虚拟化
控制面板windows组件安装hyper-v
---

## 一、环境步骤（手动 / Linux）

1. 安装Moveit2和配置助手

```bash
sudo apt update
sudo apt install ros-jazzy-moveit ros-jazzy-moveit-setup-assistant
```
2. 创建工作空间

```bash
mkdir -p ~/mockway_ws/src
cd ~/mockway_ws/src
```
3. 克隆mockway_robotics仓库

```bash
git clone https://github.com/Jelatine/mockway_robotics.git
```
4. 编译工作空间

```bash
cd ~/mockway_ws
colcon build --symlink-install
```
5. 配置环境变量

```bash
source ~/mockway_ws/install/setup.bash
```

## 二、配置Moveit2步骤

1. 启动`moveit_setup_assistant`

```bash
ros2 launch moveit_setup_assistant setup_assistant.launch.py
```
2. Start Screen

- 1️⃣选择`Create New Moveit Configuration Package`
- 2️⃣`Browse` 打开 `mockway_robotics/mockway_description/urdf/mockway_description.urdf`文件。
- 3️⃣`Load Files`

3. Self-Collisions

- 1️⃣`Generate Collision Matrix`
  
4. Planning Groups

- 1️⃣`Add Group`
- 2️⃣`Group Name` 输入 `mockway_group`
- 3️⃣`Kinematic Solver` 选择 `KDL`
- 4️⃣`Group Default Planner` 选择 `RRT`
- 5️⃣`Add Kin. Chain` 点左下角 `Expand All`
- 6️⃣`Base Link` 选择 `base_link`
- 7️⃣`Tip Link` 选择 `link6`
- 8️⃣`Save`

5. Robot Poses

- 1️⃣`Pose Name` 输入 `home`
- 2️⃣`Add Pose`
- 3️⃣`Save`

6. ROS 2 Controllers

- 1️⃣`Auto Add JointTrajectory Controller`

7. Moveit Controllers

- 1️⃣`Auto Add FollowJointTrajectory`

8. Author Information

- 1️⃣`Name`
- 2️⃣`Email`

9. Configuration Files

- 1️⃣`Browse`
- 2️⃣转到路径 `mockway_robotics/` 新建文件夹 `moveit_mockway_config`
- 3️⃣`Generate Package`
- 4️⃣`Exit Setup Assistant`

### 检查生成内容

```bash
tree src/mockway_robotics/moveit_mockway_config/
```

### 解决生成内容的问题

#### ❌ No acceleration limit was defined for joint joint1! You have to define acceleration limits in the URDF or joint_limits.yaml

编辑`joint_limits.yaml`文件

```bash
vim ~/mockway_ws/src/mockway_robotics/moveit_mockway_config/config/joint_limits.yaml
```

将所有`has_acceleration_limits`设置为`true`

将所有整型数据改为浮点型

#### ❌ No action namespace specified for controller `mockway_group_controller` through parameter `moveit_simple_controller_manager.mockway_group_controller.action_ns`

编辑`moveit_controllers.yaml`文件

```bash
vim ~/mockway_ws/src/mockway_robotics/moveit_mockway_config/config/moveit_controllers.yaml
```

在 `type: FollowJointTrajectory` 上一行增加 `action_ns: follow_joint_trajectory`

## 四、启动Moveit2

1. 安装包依赖

删除`package.xml`中的`warehouse_ros_mongo`

```bash
vim ~/mockway_ws/src/mockway_robotics/moveit_mockway_config/package.xml
```

```bash
rosdep install --from-paths src --ignore-src -r -y
```

2. 再次编译工作空间和配置环境变量

```bash
cd ~/mockway_ws
colcon build --symlink-install
source install/setup.bash
```

3. 启动模拟器

```bash
ros2 launch moveit_mockway_config demo.launch.py
```

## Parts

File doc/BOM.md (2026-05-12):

# BOM

## 结构件

| 材料 | 数量 | 备注 |
| --- | ---- | --- |
| 电机壳 | 6 | 加工 |
| 基座 | 1 | 加工 |
| 法兰 | 5 | 加工 |
| 末端 | 1 | 加工 |
| 肘部 | 1 | 加工 |
| 连杆(短) | 1 | 加工 |
| 连杆(长) | 1 | 加工 |
| 电机4310 | 4 | J1，J4，J5，J6<br>https://item.taobao.com/item.htm?id=815333472865 |
| 电机4340 | 2 | J2，J3<br>https://item.taobao.com/item.htm?id=814943831981 |
| `土八热熔螺母M3*4*4` | 60 | 36(6个壳各6个)+6(基座)+12(肘部)+6(末端)<br>https://detail.tmall.com/item.htm?id=899448134936&skuId=5922977711774 |
| `土八热熔螺母M2*3*3` | 10 | 10(5个法兰各2个) 法兰侧边防转<br>https://detail.tmall.com/item.htm?id=899448134936&skuId=5922977711783 |
| `十字平头螺丝M2*6` | 10 | 10(5个法兰各2个) 法兰侧边防转<br>https://detail.tmall.com/item.htm?id=587778806234&skuId=6161706918510 |
| `内六角螺丝钉M3*10`  | 24 | 12个上臂，12个前臂<br>https://detail.tmall.com/item.htm?id=587639753812&skuId=4763651596408 |
| `外六角螺丝M3*8` | 30 | 30(5个壳各6个) 连接法兰与壳<br>https://detail.tmall.com/item.htm?id=560233170109&skuId=5115239739933 |
| `自攻螺丝M2*5` | 24 | 24(6个壳各4个) 固定盖子<br/>https://detail.tmall.com/item.htm?id=635097264798&skuId=5800678634554 |
| `沉头十字螺丝M3*8` | 36 | 36(6个壳各6个) 壳与电机定子连接<br/>https://detail.tmall.com/item.htm?id=635369222178&skuId=5742164075947 |
| `沉头十字螺丝M3*12`  | 36 | 30(5个法兰各6个)+6(末端) 法兰/末端与电机转子连接<br/>https://detail.tmall.com/item.htm?id=635369222178&skuId=5742164075833 |
## 工具

| 材料 | 数量 | 备注 |
| --- | ---- | --- |
| `A型平键销M3*3*6` | 1 | 用于标定关节零点，加工或购买<br>https://item.taobao.com/item.htm?id=558004402273&skuId=5234867667275 |
| `开口扳手5.5mm` | 1 | 用于M3外六角螺丝，加工或购买<br>https://detail.tmall.com/item.htm?id=823964253067&skuId=5706801530492 |

## 电气材料

| 材料 | 数量 | 备注 |
| --- | ---- | --- |
| USB-CAN模块（控制方案1️⃣） | 1 | PC调试机械臂<br>https://item.taobao.com/item.htm?id=635000838271&skuId=4710513306912 |
| 树莓派5（控制方案2️⃣） | 1 | 内存8G<br />https://item.taobao.com/item.htm?id=743234145497&skuId=5128236029143 |
| CAN扩展版（控制方案2️⃣） | 1 | 2-CH CAN HAT<br />https://item.taobao.com/item.htm?id=638355987682 |
| 24V电源 | 1 | 自备 |

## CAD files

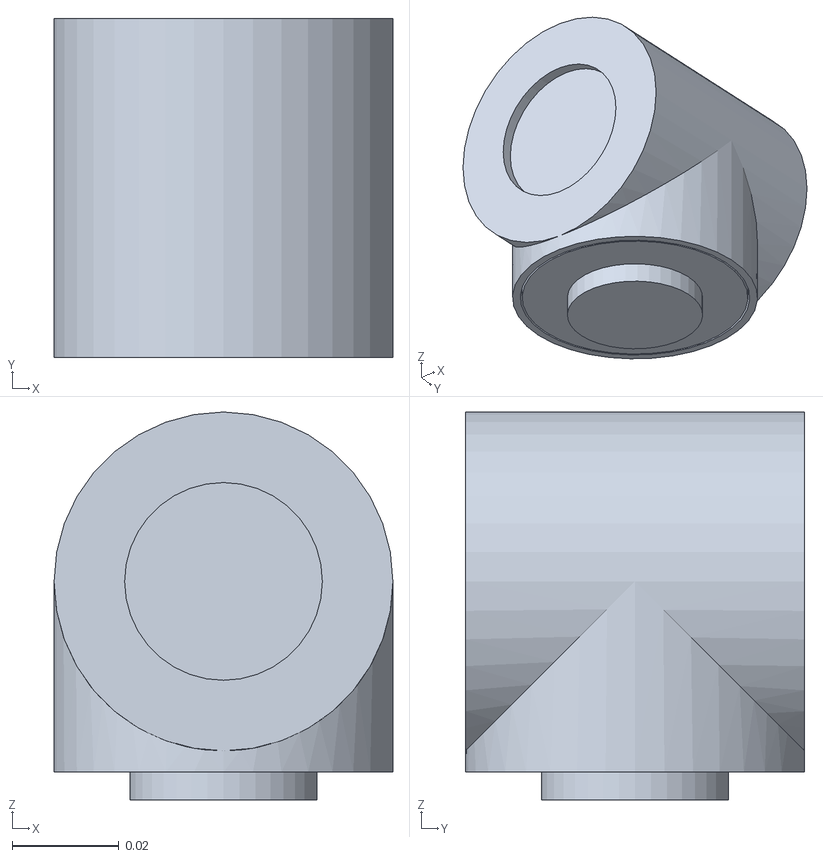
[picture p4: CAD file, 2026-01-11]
mockway_description/meshes/link5.stl
0.0634 x 0.0634 x 0.0726

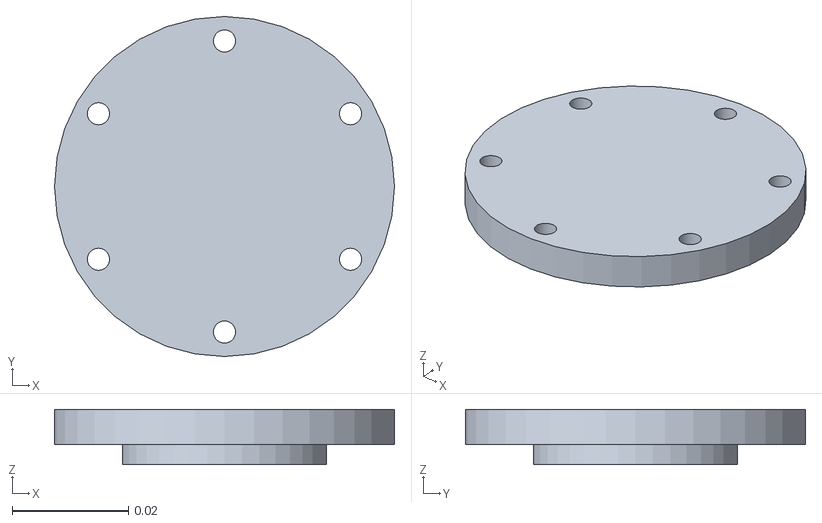
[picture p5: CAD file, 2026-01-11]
mockway_description/meshes/link6.stl
0.0584 x 0.0584 x 0.0095

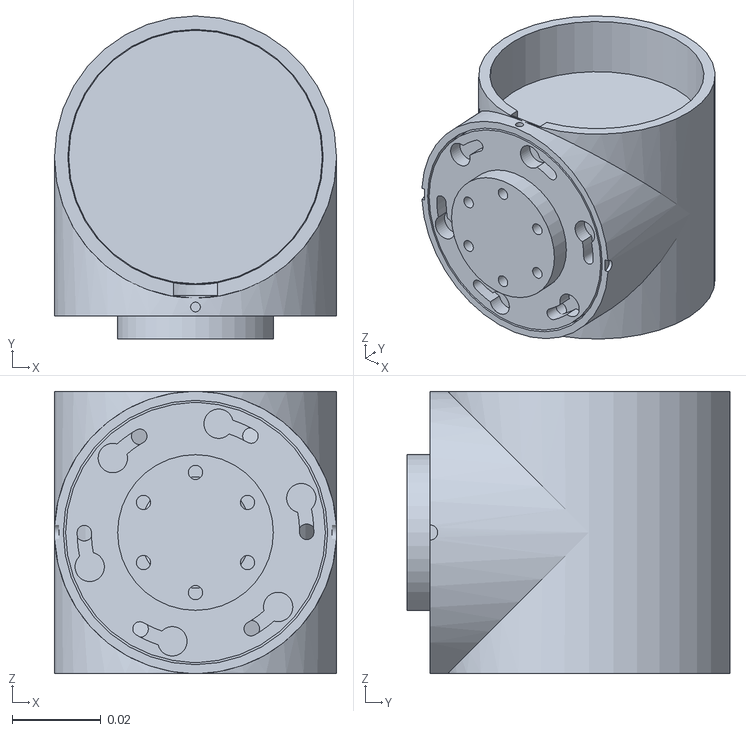
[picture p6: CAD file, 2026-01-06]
mockway_description/meshes/link1.stl
0.0634 x 0.0726 x 0.0634

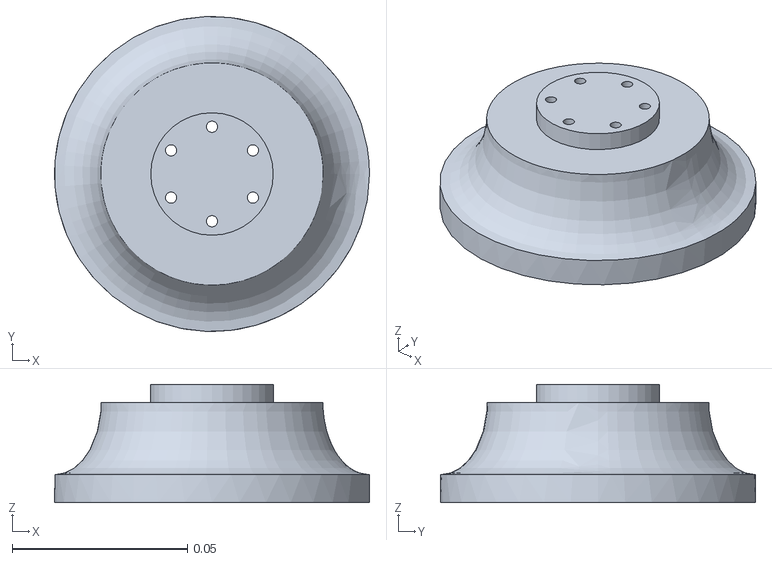
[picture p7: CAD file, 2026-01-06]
mockway_description/meshes/base_link.stl
0.09 x 0.09 x 0.0338

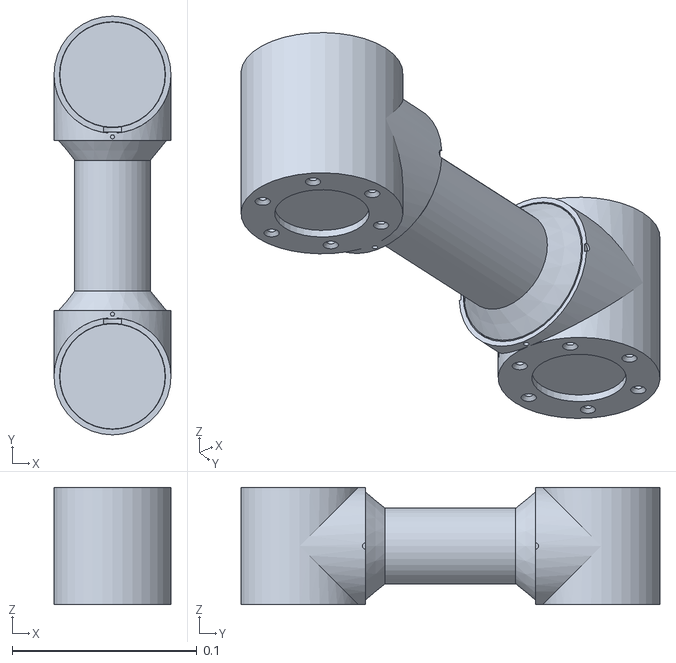
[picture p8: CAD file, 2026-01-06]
mockway_description/meshes/link2.stl
0.0634 x 0.227 x 0.0634

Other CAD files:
mockway_description/meshes/link4.stl

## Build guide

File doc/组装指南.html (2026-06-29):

# 牧卫机器人 — 组装与电机 ID 配置指南

六轴协作机械臂完整组装流程，含 6 路达妙电机 CAN ID 设置、验证与软件配置对照说明

## 系统概览

牧卫（Mockway）机械臂为开源六轴协作机械臂，共使用 6 台达妙 CAN 总线电机，通过 1 Mbps CAN 总线 与上位机通信。

关节 | 名称 | 电机型号 | CAN ID | Master ID（本项目） | 旋转方向 dir
J1 / joint1 | 基座旋转 | DM-J4310-2EC | 0x01 (1) | 0 | +1
J2 / joint2 | 肩部 | DM4340 | 0x02 (2) | 0 | +1
J3 / joint3 | 肘部 | DM4340 | 0x03 (3) | 0 | -1
J4 / joint4 | 腕部俯仰 | DM-J4310-2EC | 0x04 (4) | 0 | +1
J5 / joint5 | 腕部滚转 | DM-J4310-2EC | 0x05 (5) | 0 | +1
J6 / joint6 | 腕部偏航 / 末端 | DM-J4310-2EC | 0x06 (6) | 0 | +1

关节角正负约定：沿 URDF 定义的关节轴正方向朝外观察，逆时针旋转为关节角增大（rad +），顺时针为减小（rad −）。实物标定图见 关节旋转方向。

代码分析结论：本仓库 不包含 通过 CAN 修改电机 ID 的程序接口。电机 ID 必须在组装前，使用达妙官方调试助手逐台写入并保存到驱动器 Flash。仓库中的 motor_gui 与 dmmotor_hardware_interface 仅使用已配置好的 ID 进行通信与控制。

## 电机 ID 配置（核心）

### 为什么不能并联后一起改 ID？

CAN 总线上每台电机的 CAN_ID 必须唯一。若多台电机使用相同 ID 同时上电，总线会产生冲突，无法正确通信。因此必须每次只连接一台电机进行 ID 设置，完成后再接入下一台。

### 所需工具与连接

- 达妙科技调试助手（官方上位机，通过电机调试串口连接）
- GH1.25-3pin 调试线：连接电机调试串口与电脑 USB
- USB 转 CAN 模块（维特 USB-CAN 或达妙官方模块）：连接电机 CAN 口
- 24V 电源：为电机供电（CAN 通信需要电机上电）
- XT30(2+2) 线：电源 + CAN 四线一体插头

电脑 USB ── GH1.25 串口线 ──► 电机调试串口（参数读写） 电脑 USB ── USB-CAN ── CAN_H/CAN_L ──► 电机 CAN 口（运行验证） 24V 电源 ── XT30(2+2) ──► 电机电源接口

### 达妙调试助手操作步骤（每台电机重复一次）

1. 仅连接当前要配置的一台电机（不要接入其他电机到同一 CAN 总线）。
2. 打开达妙科技调试助手，选择正确的 COM 串口，点击 Open Port 连接。
3. 给电机上电，确认串口打印电机信息。
4. 在 Set Parameters 区域点击 Read Param，读取当前参数。
5. 设置以下关键参数：
  - CAN_ID：按上表设置为 1～6（十六进制 0x01～0x06）
  - Master ID：本项目统一使用 0（与 motor_gui、dynamics_test.yaml 默认一致）
  - Control Mode：建议设为 MIT Mode
  - CAN 波特率：固定 1 Mbps（与代码中 can_baudrate=1000000 一致）
6. 点击 Write Param 写入并保存到驱动器（断电后仍保留）。
7. 再次 Read Param 确认 CAN_ID 与 Master ID 已正确保存。
8. 断电，贴标签标明关节号与 ID，再进行下一台。

Master ID 说明：达妙官方文档建议 Master ID = CAN_ID + 0x10（例如 CAN_ID=1 时 Master=0x11），且不可设为 0x00。本 Mockway 项目在所有配置文件中统一使用 master_id: 0。若您按官方建议设置了 Master ID，则在使用 motor_gui 验证时，须将界面中的 Master ID 改为与电机一致（例如 CAN_ID=1 时填 17 即 0x11），否则无法收到反馈帧。

### 推荐配置顺序

建议按关节编号顺序配置，并在电机外壳上贴标签，避免组装后混淆：

顺序 | 贴标签 | 电机型号 | CAN_ID | Master ID（本项目）
1 | J1 | DM-J4310-2EC ×1 | 1 | 0
2 | J2 | DM4340 ×1 | 2 | 0
3 | J3 | DM4340 ×1 | 3 | 0
4 | J4 | DM-J4310-2EC ×1 | 4 | 0
5 | J5 | DM-J4310-2EC ×1 | 5 | 0
6 | J6 | DM-J4310-2EC ×1 | 6 | 0

### CAN 通信协议要点（来自代码实现）

本项目的 Python 驱动 tools/motor_gui/dm_motor_driver.py 与 C++ 硬件接口 dmmotor_hardware_interface 使用相同的达妙 MIT 协议：

- 控制帧 ID = 电机 CAN_ID（发送 MIT 控制、使能、失能、设零点等命令）
- 反馈帧 ID = 电机 Master ID（默认 0；反馈数据 D[0] 低 4 位为电机 ID）
- 使能命令：8 字节 FF FF FF FF FF FF FF FC
- 失能命令：8 字节 FF FF FF FF FF FF FF FD
- 设零点命令：8 字节 FF FF FF FF FF FF FF FE（双编码器电机此命令无效，Mockway 使用 DM4310/4340 双编码器型号）
- 位置-速度模式：帧 ID = 0x100 + motor_id
- 速度模式：帧 ID = 0x200 + motor_id

## ID 验证与调试

每台电机 ID 写入后，或全部组装完成上电前，使用项目自带的图形调试工具验证：

python tools/motor_gui/motor_gui.py

### 单电机验证步骤

1. 仅连接一台待测电机到 USB-CAN 适配器。
2. 打开 motor_gui.py，配置：
  - USB-CAN 类型：达妙官方模块选「达妙 USB-CAN」，维特模块选「维特 USB-CAN」
  - COM 口：Windows 为 COMx，Linux 为 /dev/ttyUSB0（须为 USB-CAN 模块口，非电机调试串口）
  - 串口波特率：921600
  - 电机类型：J1/J4/J5/J6 选 DM-J4310-2EC，J2/J3 选 DM4340
  - 电机 ID：对应 1～6
  - Master ID：0（填 0 时按反馈数据内 ID 自动匹配）
3. 点击「连接」。若 3 秒内收到反馈，说明 ID 与接线正确。
4. 点击「使能电机」，用正转/反转按钮测试运动，并记录该关节电机正转时位置读数是增大还是减小（用于确定 direction，见 关节旋转方向）。

motor_gui 调试界面

motor_gui 单电机调试界面

### 六电机总线验证

全部电机 ID 唯一且 CAN 总线正确菊花链连接后，逐台修改 GUI 中的电机 ID（1→6）重复连接测试。也可在 Linux 下使用：

candump can0   # 应能看到各 ID 的反馈帧

### 力矩补偿测试（整臂联调）

完成六电机 ID 验证、机械组装及关节零点标定后，可通过实时力矩补偿程序验证整臂通信、动力学模型与重力补偿是否正常。该步骤在单电机 motor_gui 调试之后、运行 MoveIt 之前进行。

安全警告：力矩模式若准备不充分易发生飞车（失控）。首次测试务必清空工作区、手边可及紧急断电，并严格按下列顺序操作。

#### 1. 安装依赖

Windows：请直接跳到下方「Windows 推荐：用 Miniconda 安装 Pinocchio」，不要对完整 requirements.txt 执行 pip。

Linux：可尝试：

cd tools/dynamics_test
pip install -r requirements.txt -i https://pypi.tuna.tsinghua.edu.cn/simple

依赖包括 pinocchio（刚体动力学）、numpy、matplotlib。Linux 下也可使用 conda：

conda create -n mockway_dynamics python=3.10 -y
conda activate mockway_dynamics
conda install pinocchio -c conda-forge -y
pip install -r requirements.txt

#### pip 使用国内镜像源（下载过慢时）

若默认 PyPI 源速度较慢，可在单次命令中通过 -i 指定国内镜像：

# 清华大学（常用）
pip install -r requirements.txt -i https://pypi.tuna.tsinghua.edu.cn/simple

# 阿里云
pip install -r requirements.txt -i https://mirrors.aliyun.com/pypi/simple/

# 中国科技大学
pip install -r requirements.txt -i https://pypi.mirrors.ustc.edu.cn/simple/

# 腾讯云
pip install -r requirements.txt -i https://mirrors.cloud.tencent.com/pypi/simple

安装单个包时同样适用，例如：

pip install pyserial -i https://pypi.tuna.tsinghua.edu.cn/simple

若提示 SSL/证书相关警告，可追加 --trusted-host（以清华源为例）：

# Linux / macOS
pip install -r requirements.txt \
  -i https://pypi.tuna.tsinghua.edu.cn/simple \
  --trusted-host pypi.tuna.tsinghua.edu.cn

# Windows（CMD / PowerShell 单行）
pip install -r requirements.txt -i https://pypi.tuna.tsinghua.edu.cn/simple --trusted-host pypi.tuna.tsinghua.edu.cn

如需永久生效，可写入 pip 配置文件，之后普通 pip install 即走国内源：

系统 | 配置文件路径
Windows | %APPDATA%\pip\pip.ini
Linux / macOS | ~/.pip/pip.conf

[global]
index-url = https://pypi.tuna.tsinghua.edu.cn/simple
trusted-host = pypi.tuna.tsinghua.edu.cn

motor_gui 依赖安装示例：

cd tools/motor_gui
pip install -r requirements.txt -i https://pypi.tuna.tsinghua.edu.cn/simple

Windows 用户注意：dynamics_test 依赖的 pin（Pinocchio）在 Windows 上常常没有可用的 pip 预编译包，pip install -r requirements.txt 会卡在 Installing build dependencies ...（实为后台下载/编译 C++ 依赖，无进度条，可能数十分钟仍失败）。请勿在 Windows 上用 pip 安装 Pinocchio，请改用下方 conda 方案。

#### Windows 推荐：用 Miniconda 安装 Pinocchio

可双击运行项目自带管理脚本（含菜单：1 安装 / 2~4 启动工具 / 5 工作 shell / 6 停止；未安装 Miniconda 时会自动下载安装）：

tools\setup_win.bat

安装完成后从菜单选择对应工具即可。也可命令行：

cd tools
setup_win.bat setup      REM 仅安装
setup_win.bat motor_gui  REM 电机调试
setup_win.bat torque     REM 实时力矩补偿
setup_win.bat inverse    REM 离线动力学测试
setup_win.bat shell      REM 打开工作 shell
setup_win.bat stop       REM 关闭工具窗口

也可手动执行以下步骤。1. 安装 Miniconda (https://docs.conda.io/en/latest/miniconda.html)（或 Anaconda）后，打开 Anaconda Prompt，执行：

conda create -n mockway_dynamics python=3.10 -y
conda activate mockway_dynamics
conda install pinocchio -c conda-forge -y

cd 你的路径\mockway_robotics\tools\dynamics_test
pip install numpy matplotlib pyserial pyyaml -i https://pypi.tuna.tsinghua.edu.cn/simple

2. 验证 Pinocchio 是否可用：

python -c "import pinocchio; print('pinocchio OK', pinocchio.__version__)"

3. 之后运行力矩补偿前，每次先 conda activate mockway_dynamics。

说明：motor_gui 只需 pyserial，继续用普通 pip 即可；仅力矩补偿需要 Pinocchio，因此 Windows 上分开环境安装最省事。

#### 2. 配置文件

编辑 tools/dynamics_test/dynamics_test.yaml，确保与电机实际 ID、接线一致：

can:
  port: "COM8"              # 改为你的 USB-CAN COM 口（与 motor_gui 相同）
  adapter_type: "damiao"    # USB-CAN 控制器：damiao=达妙，witmotion=维特（须与 motor_gui 一致）
  serial_baudrate: 921600
  can_baudrate: 1000000

motors:
  - id: 1
    type: "DM_J4310_2EC"
    master_id: 0
    direction: 1
  - id: 2
    type: "DM4340"
    ...
  - id: 3
    type: "DM4340"
    direction: -1          # J3 反向，与 ros2_control 一致
  # id 4~6 略

control:
  rate: 100
  compensation_mode: "gravity"
  torque_scale: 1.0              # 未单独指定时的全局 fallback
  gravity_torque_scale: 1.0      # 纯重力 g(q) 全局倍率 → 菜单「1. 启动重力补偿」
  full_dynamics_torque_scale: 0.35  # 完整动力学全局倍率 → 菜单「2. 启动完整动力学补偿」
  hold_inactive_joints: true
  mit_params:
    kp: 0.0                      # 补偿关节纯 t_ff
    kd: 0.0

motors:
  - id: 2
    type: "DM4340"
    compensation_enabled: true
    gravity_torque_scale: 1.2       # 纯重力：悬停支撑（宜接近 motor_gui 标定值）
    full_dynamics_torque_scale: 0.2 # 完整动力学：拖动示教（宜偏小，防抖动）

六路电机 ID、型号、direction 须与上文「软件中的 ID 映射」及 mockway_description.ros2_control.xacro 完全一致。纯重力与完整动力学须分开标定倍率，详见 分模式力矩倍率。

#### 3. 测试前检查清单

- 机械结构与 URDF 模型一致，各关节零点已标定
- 24V 供电、CAN 菊花链及 120Ω 终端电阻已接好
- 六台电机均已通过 motor_gui 单电机/总线验证
- 工作区无障碍物，可快速切断电源

#### 4. 力矩值预验证（推荐）

首次运行前，可在 realtime_torque_compensation.py 中暂时注释 controller.enable_motors()，先启动程序观察 Pinocchio 计算的力矩值是否在合理范围（J1/J4/J5/J6 约 ±10 Nm 内，J2/J3 约 ±28 Nm 内）。确认无误后再恢复使能。

#### 5. 运行重力补偿测试

cd tools/dynamics_test
python realtime_torque_compensation.py

进入交互菜单后：

1. 选择 「1. 启动重力补偿」（对应 compensation_mode: "gravity"，仅补偿重力项 τ = g(q)）
2. 手动缓慢拖动各关节，机械臂应接近「失重」感，无明显下坠或猛甩
3. 测试完成后选择 「3. 停止补偿」，再选 「0. 退出」；也可随时按 Ctrl+C 紧急停止

也可直接以演示模式启动（跳过菜单）：

python realtime_torque_compensation.py --demo gravity
python realtime_torque_compensation.py --can-port COM8   # 覆盖 yaml 中的端口
python realtime_torque_compensation.py --can-adapter damiao  # 覆盖适配器类型

力矩补偿运行界面

实时力矩补偿程序运行界面（重力补偿模式）

#### 6. 补偿模式说明

模式 | 菜单选项 | 补偿内容 | 适用场景
gravity | 1. 启动重力补偿 | 仅重力 g(q) | 悬停支撑、静态姿态验证；使用 gravity_torque_scale
full_dynamics | 2. 启动完整动力学补偿 | 惯性 + 科氏 + 离心 + 重力 | 拖动示教、快速运动；使用 full_dynamics_torque_scale（通常更小）
none | — | 无补偿 | 对比测试

#### 7. 预期现象与异常处理

- 正常：重力补偿开启后，各关节可轻松用手推动，松手后无明显剧烈摆动
- 某关节反力过大/过小：检查该关节 direction 是否与 xacro 一致；复查零点标定
- 抖动或飞车：完整动力学模式倍率过大时易抖，请降低 full_dynamics_torque_scale；重力模式用 gravity_torque_scale。确认补偿关节为纯 t_ff（kp=0, kd=0）；逐轴调试时开启 hold_inactive_joints（见 分模式力矩倍率、URDF 质量与重力补偿）
- 无法连接电机 / 出现「进入AT指令模式」警告：说明当前使用了维特协议，而硬件是达妙 USB-CAN。在 dynamics_test.yaml 中设置 can.adapter_type: "damiao"，与 motor_gui 下拉框一致
- 无法连接电机：核对 dynamics_test.yaml 中 can.port、can.adapter_type、电机 ID；关闭占用 COM 口的其他程序（含达妙助手、motor_gui）

说明：离线动力学仿真（不连硬件）可运行 python inverse_dynamics_test.py，用于验证 URDF 与 Pinocchio 模型；整臂联调以 realtime_torque_compensation.py 为准。URDF 质量与分模式力矩倍率见 URDF 质量与重力补偿。

## URDF 质量与重力补偿

实时力矩补偿程序（realtime_torque_compensation.py）通过 Pinocchio 读取 URDF 中的连杆质量、质心、惯量，根据当前关节角 q 计算模型力矩，再经分模式力矩倍率修正后发给电机。因此 URDF 质量是否接近实物，以及各模式下的倍率标定，直接决定补偿是否安全有效。

### 质量在哪里设置？

主文件（须优先修改）：

mockway_description/urdf/mockway_description.urdf

MoveIt 使用的 xacro 仅引用上述 URDF，不在 xacro 里单独写质量：

moveit_mockway_config/config/mockway_description.urdf.xacro
  → include mockway_description/urdf/mockway_description.urdf

力矩补偿程序同样加载该 URDF 路径（见 realtime_torque_compensation.py 中的 mockway_description/urdf/mockway_description.urdf）。

注意：仓库中 mockway_lua_moveit/ui/public/urdf/mockway_description.urdf 等副本可能与主 URDF 质量不一致；以 mockway_description/urdf/ 为准，修改后如需 Web 预览再同步副本。

### URDF 中的写法

每个连杆 <link> 内都有 <inertial> 块。以 J2 对应连杆 link2 为例：

<link name="link2">
  <inertial>
    <mass value="0.568"/>                              <!-- 质量 (kg)，主要改这里 -->
    <origin xyz="0.000 0.035 0.069" rpy="0 0 0"/>   <!-- 质心相对 link 坐标系 (m) -->
    <inertia ixx="0.002661" iyy="0.000305" izz="0.002654"
             ixy="-0.000000" ixz="-0.000000" iyz="-0.000043"/>  <!-- 惯量 (kg·m²) -->
  </inertial>
  ...
</link>

各字段含义：

字段 | 含义 | 对重力补偿的影响
mass | 连杆质量 (kg) | 最主要：质量越大，下游关节所需补偿力矩越大
origin xyz | 质心位置 (m) | 决定力臂：质心离关节轴越远，重力矩越大
inertia ixx…izz | 转动惯量 | 纯重力补偿 g(q) 几乎不用；完整动力学补偿时才重要
visual / collision 中的 mesh | 显示与碰撞网格 | 不会自动参与动力学计算；改 STL 不会改质量，须手动改 inertial

### 本机 Mockway 默认质量一览

以下为当前 mockway_description.urdf 中各 link 的 mass（单位 kg）：

连杆 (link) | 对应关节 | 结构件说明 | 默认 mass (kg)
base_link | —（基座） | base | 0.097
link1 | J1 | 基座旋转段 + 电机壳等 | 0.378
link2 | J2 | 上臂大臂段（J2 之后整段重量） | 0.568
link3 | J3 | 上臂远端 + 肘部连杆 | 0.488
link4 | J4 | 前臂段 | 0.378
link5 | J5 | 腕部段 | 0.378
link6 | J6 | 末端法兰 / tail | 0.016

Pinocchio 会把当前姿态下所有下游 link 的重力，折算到每个关节的 g(q) 上。例如 J2 的补偿力矩不仅取决于 link2 的质量，还取决于 J3～J6 及末端负载的总重与姿态。

### 分模式力矩倍率（gravity / full_dynamics）

纯重力补偿与完整动力学补偿对力矩大小需求不同，共用同一倍率往往无法两者兼顾：

补偿模式 | 模型输出 | 典型用途 | 倍率特点
gravity | 仅 g(q) | 悬停、静态支撑、验证 URDF 重量 | 倍率宜偏大（如 J2 约 1.2），使松手后不下坠
full_dynamics | M(q)·a + C(q,v) + g(q) | 拖动示教、快速运动跟随 | 倍率宜偏小（如 J2 约 0.2），否则惯性/科氏项叠加后易抖动；过小则拖动手感重、不足以单独支撑机械臂

程序在切换菜单「1. 重力补偿 / 2. 完整动力学补偿」时，自动选用对应倍率，无需改 yaml 中的 compensation_mode 后再重启（启动控制时会打印当前模式各关节有效倍率）。

#### 配置文件项

有效倍率 = 全局倍率 × 关节倍率。未写模式专用项时，回退到 torque_scale。

配置项 | 作用域 | 用于模式
control.gravity_torque_scale | 全局 | gravity
control.full_dynamics_torque_scale | 全局 | full_dynamics
motors[].gravity_torque_scale | 单关节 | gravity
motors[].full_dynamics_torque_scale | 单关节 | full_dynamics
control.torque_scale / motors[].torque_scale | 全局 / 单关节 | 上述未指定时的 fallback

# dynamics_test.yaml 示例（Mockway J2 实测参考）
control:
  gravity_torque_scale: 1.0
  full_dynamics_torque_scale: 0.35

motors:
  - id: 2
    compensation_enabled: true
    gravity_torque_scale: 1.2       # 纯重力：悬停约需 motor_gui ~0.5 Nm 时标定
    full_dynamics_torque_scale: 0.2 # 完整动力学：拖动示教手感合适

#### 标定建议

1. 重力模式：菜单选「1. 启动重力补偿」，用 motor_gui 在同一姿态找悬停力矩，调节 gravity_torque_scale 直至松手近似不下坠。
2. 完整动力学模式：菜单选「2. 启动完整动力学补偿」，从较小倍率（如 0.15～0.3）试起，缓慢拖动各关节；若抖动则再减小，若拖动过沉则略增大。
3. 两种模式分别标定，不要共用同一 torque_scale。

### 程序如何用力矩（计算链）

编码器 θ_motor ↓ × direction 关节角 q ↓ Pinocchio（gravity 模式：g(q)；full_dynamics：M·a+C+g） 模型力矩 τ_model（随 q、v、a 变化，单位 Nm） ↓ × 当前模式倍率（gravity_torque_scale 或 full_dynamics_torque_scale） 补偿指令 τ_cmd ↓ × direction → MIT 模式 t_ff 发给电机

模型力矩是根据 URDF 与当前姿态算出来的；模式倍率是 motor_gui / 拖动手感标定的经验修正。

### 力矩倍率与 URDF 质量的关系

若 URDF 质量准确，各关节模式倍率应接近合理标定值（重力模式常接近 1.0，完整动力学通常更小）。若重力模式也需要远小于 1 的系数，说明模型重力矩明显大于真机，常见原因包括：

- 打印件实际重量与 CAD/URDF 不一致（填充率、材料、未计入螺丝/线材）
- 末端工具、夹具、线缆未写入 URDF（应加在 link6 或新建 tool link）
- 质心 origin 偏差导致力臂过大
- 传动摩擦、效率等 URDF 无法建模（只能用模式倍率近似）

#### 用 motor_gui 标定 gravity_torque_scale

1. 在固定姿态下，用 motor_gui 只连目标关节，启动力矩控制，从 0 Nm 缓慢调节。
2. 找到使关节近似悬停的力矩，记为 τ_实测（例如 J2 约 0.5 Nm）。
3. 运行力矩补偿重力模式，将 gravity_torque_scale 暂设为 1.0，查看 Pinocchio 输出的 τ_模型。
4. 计算：gravity_torque_scale ≈ τ_实测 ÷ τ_模型，写入 motors[].gravity_torque_scale。
5. full_dynamics_torque_scale 在菜单「2. 完整动力学补偿」下单独从较小值试起，按拖动手感微调。

### 如何正确修改 URDF 质量

#### 方法一：称重（推荐）

1. 理解 URDF 中每个 link 的质量通常包含该关节之后整段结构的等效质量（按 CAD 导出惯例），不是「单独一个打印件」。
2. 用电子秤称量实物各段（含电机、壳体、连杆、线材），与表中默认值对比。
3. 若仅某段偏重，修改对应 link 的 mass value；若末端加了夹具，优先增大 link6 的 mass，或增加新的 tool link。
4. 保存 URDF 后运行 python inverse_dynamics_test.py 查看各姿态下 g(q) 是否合理。
5. 再用 realtime_torque_compensation.py 验证；gravity_torque_scale 应逐步接近 1.0。

#### 方法二：按比例缩放（快速试凑）

若重力模式标定倍率明显小于 1，可尝试把影响该关节的主要 link 质量乘以相近比例，再测试。此法粗糙，仍建议称重。

#### 修改示例

将 J2 段质量从 0.568 kg 改为称重值 0.45 kg：

<link name="link2">
  <inertial>
    <mass value="0.45"/>   <!-- 原 0.568 -->
    ...
  </inertial>

建议优先级：先保证 direction 与零点正确 → 分模式标定 gravity_torque_scale / full_dynamics_torque_scale → 有时间再按称重修正 URDF，使重力倍率回归 1.0。

### 验证修改是否生效

cd tools/dynamics_test
conda activate mockway_dynamics    # Windows 用户

# 离线查看各姿态重力矩
python inverse_dynamics_test.py

# 单姿态快速查看（示例：J2=30°）
python -c "
import pinocchio as pin
import numpy as np
from pathlib import Path
urdf = Path('../../mockway_description/urdf/mockway_description.urdf')
model = pin.buildModelFromUrdf(str(urdf))
data = model.createData()
q = np.array([0, np.deg2rad(30), 0, 0, 0, 0])
g = pin.computeGeneralizedGravity(model, data, q)
print('g(q) [Nm]:', g)
print('J2 (index 1):', g[1])
"

修改 URDF 后无需重新编译，重启 realtime_torque_compensation.py 即可加载新质量。

## 软件中的 ID 映射

以下配置文件中的 ID 必须与电机实际 CAN_ID 一致，否则 MoveIt / 力矩补偿无法正常工作：

### 关节旋转方向（direction / dir）

URDF、Pinocchio、MoveIt 中的关节角 q（单位 rad）遵循统一约定：

- 沿该关节 URDF 定义的轴正方向朝外观察（右手系）：逆时针转动 → q 增大（rad +）；顺时针转动 → q 减小（rad −）。
- 达妙电机反馈的原始位置 θmotor 正负由转子实际安装方向决定，与关节正方向不一定相同。

实物标定图：下方三张图在仓库 doc/img/ 中保存，由脚本根据实物照片自动生成，标注各关节默认 dir 与 CCW 正方向，便于对照 motor_gui 正转验证。

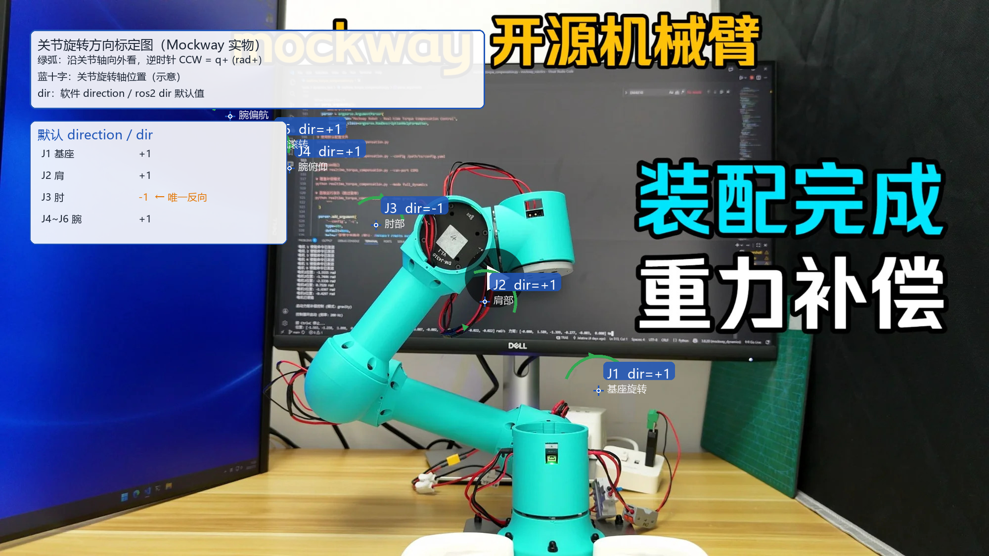
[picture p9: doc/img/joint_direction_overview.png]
Mockway 实物关节方向总览


图 1 — 整臂实物标定总览（基于 cover.jpg）。蓝十字为关节旋转轴示意位置；绿弧表示沿轴向外看时的 CCW = q+。标签中 dir=±1 为本仓库默认 direction / dir；J3 为唯一默认 −1。

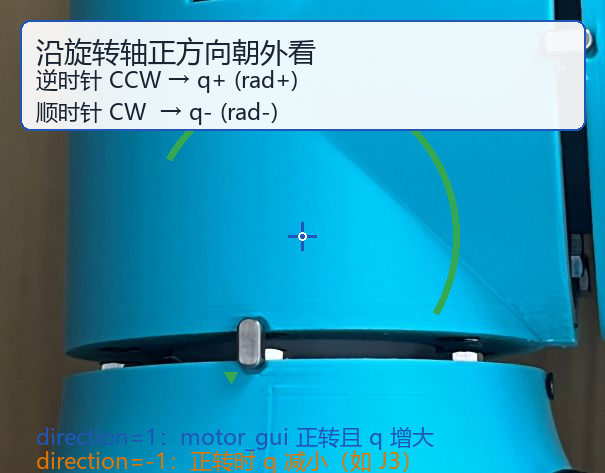
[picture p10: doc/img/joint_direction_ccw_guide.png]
沿轴向外看 CCW 为正


图 2 — 单关节 CCW 正方向（基于 calibrate_joint.jpg）。适用于任意关节：沿轴正方向朝外看，逆时针为 rad+。

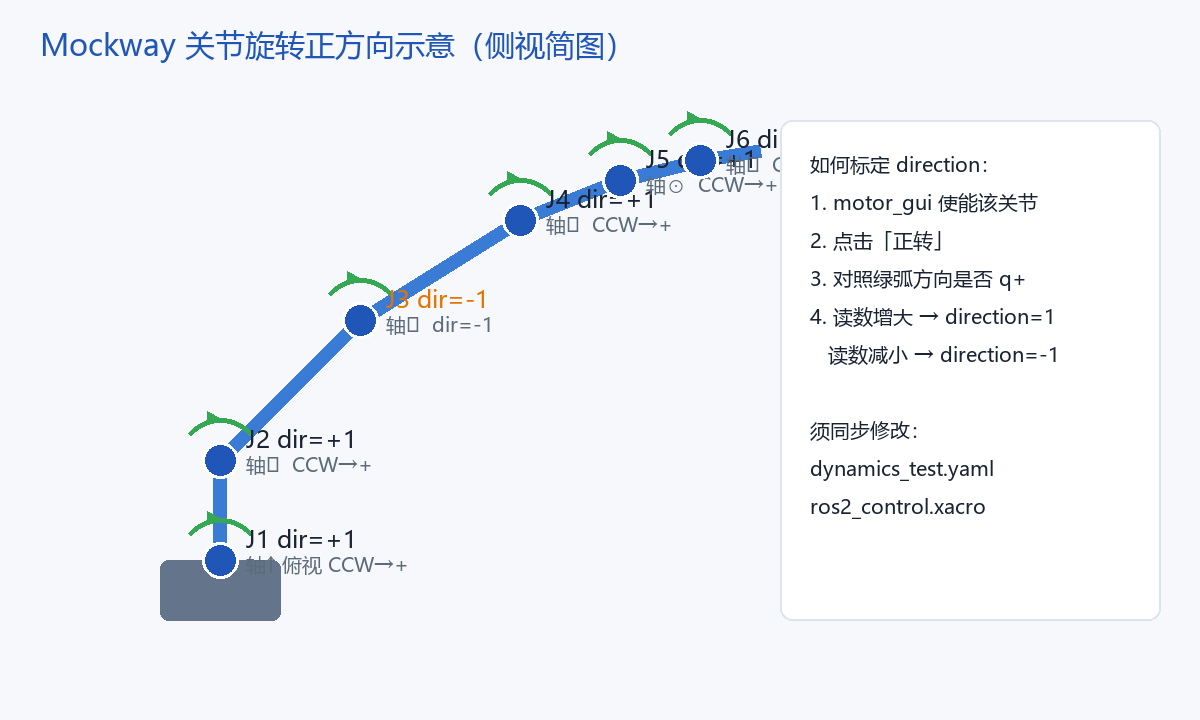
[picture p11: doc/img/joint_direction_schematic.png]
侧视简图与 direction 标定步骤


图 3 — 侧视简图 + 标定步骤。汇总 J1～J6 默认 dir，以及 motor_gui 正转时如何判断 direction。

重新生成标注图（修改关节位置或更换照片后）：

pip install pillow
python doc/tools/generate_joint_direction_images.py

源图：doc/img/cover.jpg、doc/img/calibrate_joint.jpg；输出：joint_direction_overview.png、joint_direction_ccw_guide.png、joint_direction_schematic.png。

软件中用 direction（dynamics_test.yaml）或 dir（ros2_control.xacro）把电机读数换算为关节角：

q_joint = direction × θ_motor

direction =  1   # 电机读数增大时，关节角也增大（与 URDF 正方向一致）
direction = -1   # 电机读数增大时，关节角减小（与 URDF 正方向相反）

如何确定 direction：零点标定后，在 motor_gui 中使能该关节，观察正转时反馈位置变化：

1. 若正转使该关节按 URDF 定义逆时针（关节角应增大），且读数增大 → 设 direction: 1。
2. 若正转使关节逆时针但读数减小（或正转对应顺时针）→ 设 direction: -1。

不同机械臂的法兰安装、减速器出轴方向、壳体相对 link 的固定方式都可能不同，不能假设所有关节均为 +1。Mockway 本仓库默认 J3 为 -1，其余为 +1；若您更改了结构件安装方式或复刻时镜像了某关节，须逐关节用上述方法验证并同步修改 dynamics_test.yaml 与 mockway_description.ros2_control.xacro 中的 direction / dir，否则 MoveIt 与重力补偿会出现反向运动或猛冲。

### 1. ROS2 硬件接口（MoveIt 主配置）

文件：moveit_mockway_config/config/mockway_description.ros2_control.xacro

<!-- Joint 1 -->
<param name="can_id">0x01</param>  <param name="type">1</param>  <!-- DM4310 -->
<!-- Joint 2 -->
<param name="can_id">0x02</param>  <param name="type">3</param>  <!-- DM4340 -->
<!-- Joint 3 -->
<param name="can_id">0x03</param>  <param name="type">3</param>  <param name="dir">-1</param>
<!-- Joint 4~6: can_id 0x04~0x06, type=1 -->

电机类型枚举：1=DM4310，3=DM4340。USB-CAN 默认端口 /dev/ttyUSB0，波特率 921600。

### 2. 力矩补偿 / 动力学测试

文件：tools/dynamics_test/dynamics_test.yaml

motors:
  - id: 1
    type: "DM_J4310_2EC"
    master_id: 0
    direction: 1
  - id: 2
    type: "DM4340"
    ...
  - id: 3
    type: "DM4340"
    direction: -1

### 3. Python 驱动构造参数

motor = DMMotor(
    can_adapter=can_adapter,
    motor_id=1,      # CAN 命令帧 ID
    master_id=0,     # 反馈帧 ID
    motor_type=MotorType.DM_J4310_2EC
)

## 电气连接

电气拓扑图

- 6 台电机 CAN 总线菊花链连接（CAN_H 接 CAN_H，CAN_L 接 CAN_L）
- CAN 总线两端各接 120Ω 终端电阻
- CAN 波特率：1 Mbps
- USB-CAN 适配器串口波特率：921600（维特模块，见 README）
- 供电：24V 统一电源

注意：在仅通过 USB-CAN 逐台调试 ID 时，不需要将所有电机并联；全部 ID 配置完成后再进行总线级联与终端电阻安装。

## JellyCAD 导出 STEP（3D 打印）

本项目的结构件使用 JellyCAD v0.3.10 (https://github.com/Jelatine/JellyCAD/releases/tag/v0.3.10) 参数化建模，脚本位于仓库 jellycad_src/ 目录。开启 STEP 导出配置后，用 JellyCAD 打开对应脚本并运行，即可在目录下生成可用于 3D 打印的 STEP 文件。

### 1. 开启 STEP 导出

编辑 jellycad_src/config.lua，确认：

config.generate_step_file = true   -- true：运行各零件脚本时自动生成 STEP，用于 3D 打印

设为 false 时，脚本仅预览模型，不写 STEP 文件。

### 2. 用 JellyCAD 打开并运行

1. 安装并启动 JellyCAD v0.3.10。
2. 在 JellyCAD 中打开 jellycad_src/ 下的 .lua 文件（建议将整个 jellycad_src 作为工作目录，以便 require('config') 正常加载）。
3. 按 F5 运行当前脚本（或菜单「运行」）。
4. 当 generate_step_file = true 时，脚本末尾会调用 export_step()，STEP 文件输出到 当前工作目录（通常为 jellycad_src/）。

提示：修改臂长、壁厚等参数时，只需编辑 config.lua 后重新 F5 运行对应零件脚本，STEP 会按新参数重新生成。

### 3. 各脚本与输出文件

Lua 脚本 | 输出 STEP 文件 | 说明
base.lua | base.step | 基座
flank.lua | flank.step | 法兰（多处共用）
shell.lua | shell.step | 电机外壳
linkage.lua | upper_arm.step、fore_arm.step | 上臂 / 前臂连杆
elbow.lua | elbow.step | 肘部结构
tail.lua | tail.step | 末端平台
lid.lua | lid.step | 端盖
camera.lua | camera.step | 相机支架（可选）
combine.lua | — | 整机装配与 URDF 导出；结构 STEP 仍由上述各零件脚本生成

脚本中的典型导出写法如下（以 base.lua 为例）：

if config.generate_step_file then
    -- 生成 STEP 文件用于 3D 打印
    model_base():color('turquoise'):export_step('base.step')
end

### 4. 导入切片软件

- 将生成的 .step 导入 Bambu Studio、PrusaSlicer、Cura 等切片软件。
- 若切片器不支持 STEP，可在 JellyCAD 中对同一模型额外调用 export_stl('part.stl')，或经 FreeCAD 转换后切片。
- 建议打印填充率 ≥ 40%，Gyroid 填充（见下方「组装前准备」）。

### 5. 不想自己导出时

已上传 MakerWorld，可直接下载现成切片工程：Mockway 开源六轴协作机械臂 (https://makerworld.com.cn/zh/models/2037149-mockway-kai-yuan-liu-zhou-xie-zuo-ji-jie-bi)。

注意：*.step / *.stl 为本地生成物，已在仓库 .gitignore 中忽略，不会提交到 Git。

## 组装前准备

- 完成上述 6 台电机 ID 配置与单电机验证
- 3D 打印全部结构件：自行按 JellyCAD 导出 STEP 生成后打印，或参见 BOM.md / MakerWorld (https://makerworld.com.cn/zh/models/2037149-mockway-kai-yuan-liu-zhou-xie-zuo-ji-jie-bi)
- 准备 BOM 中列出的螺丝、热熔螺母、线材与工具
- 建议打印填充率 ≥ 40%，Gyroid 填充

## 1嵌入所有热熔螺母

工具：电烙铁

### M2 热熔螺母

材料：flange.lua 结构件 5 个、土八热熔螺母 M2×3×3 共 10 个

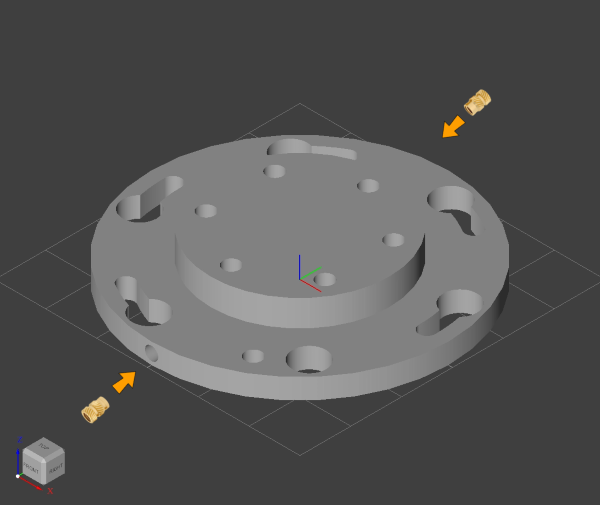
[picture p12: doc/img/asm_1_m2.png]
M2 热熔螺母


### M3 热熔螺母

材料：shell.lua 6 个、tail.lua 1 个、base.lua 1 个、elbow.lua 1 个、土八热熔螺母 M3×4×4 共 60 个

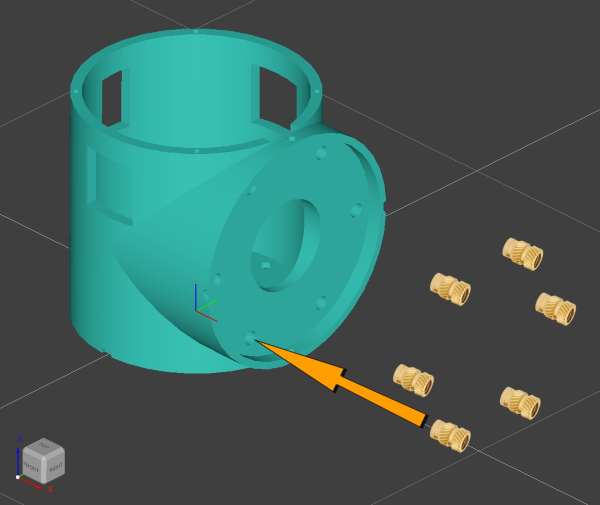
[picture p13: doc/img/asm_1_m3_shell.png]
shell


shell

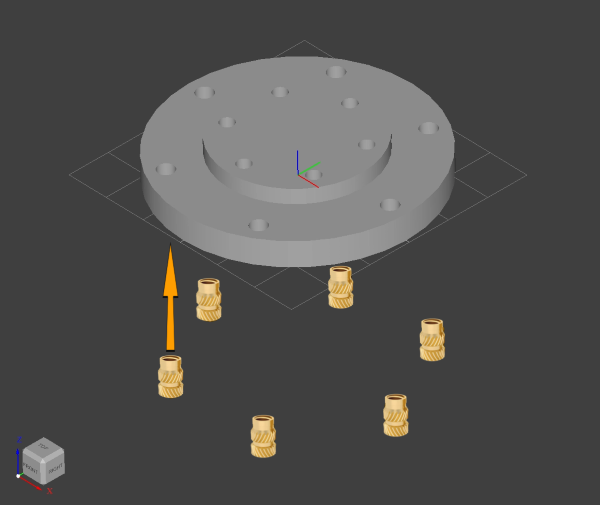
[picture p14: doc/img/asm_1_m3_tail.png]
tail


tail

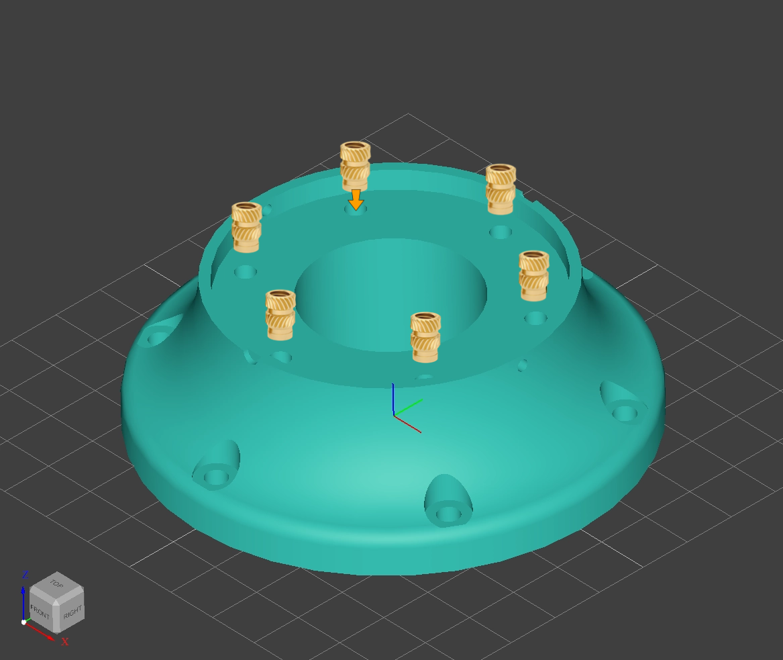
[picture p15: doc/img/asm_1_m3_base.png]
base


base

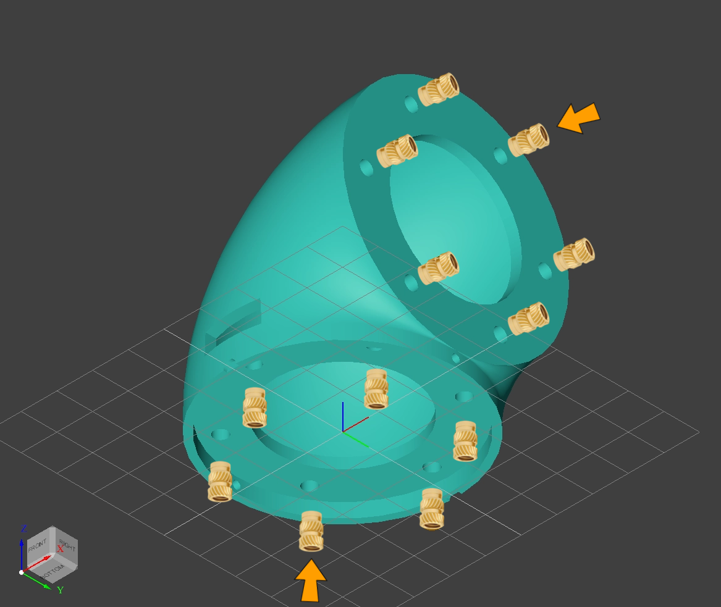
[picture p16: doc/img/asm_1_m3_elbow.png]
elbow


elbow

## 2安装所有电机到 shell

材料：shell.lua 6 个、DM4310 电机 4 个（J1/J4/J5/J6）、DM4340 电机 2 个（J2/J3）、沉头十字螺丝 M3×8 共 36 个

工具：十字螺丝刀

安装前确认每台电机外壳已贴好 J1～J6 标签，对应 ID 1～6，避免后续接线混淆。

电机入壳

## 3安装所有法兰到电机转子

材料：装完电机的 shell 6 个、flange.lua 5 个、tail.lua 1 个、沉头十字螺丝 M3×12 共 36 个

工具：十字螺丝刀

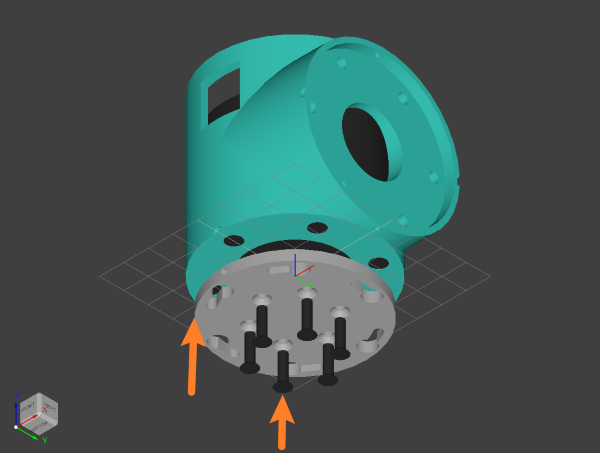
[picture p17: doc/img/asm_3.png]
法兰安装


## 4安装关节 1 到基座

材料：base.lua 1 个、DM4310 关节（J1）1 个、外六角螺丝 M3×8 共 6 个、十字平头螺丝 M2×6 共 2 个

工具：开口扳手 5.5 mm、十字螺丝刀

1. 将外六角螺丝 M3×8 预先拧入 base.lua 的热熔螺母（不必完全拧紧）。
2. 法兰两侧 M2 热熔螺母对准基座 M2 通孔，沿圆弧槽旋转，使法兰大孔对准外六角螺丝头。
3. 所有螺丝头穿过关节法兰后，将螺丝转入法兰圆弧槽内。
4. 用十字平头螺丝 M2×6 穿过基座 M2 通孔，固定在关节上。
5. 用开口扳手 5.5 mm 将外六角螺丝拧紧在基座上。

## 5组装上臂

材料：DM4340 关节（J2、J3）2 个、linkage.lua（长）1 个、内六角螺丝钉 M3×10 共 12 个、XT30(2+2) 线 2 根、导线若干、焊锡、热缩管或电工胶布

工具：电烙铁、内六角扳手

1. 将 XT30(2+2) 线插入关节 2，导线经电机上方剩余导线孔穿入 shell 内。
2. 关节 3 同上。
3. 将 4 条延长线插入 linkage.lua（长）的导线孔。
4. 延长线两端分别经 J2、J3 法兰槽通孔穿入 shell，至电机顶部。
5. 焊接所有导线（注意 CAN_H/CAN_L 极性一致）。
6. 用内六角螺丝 M3×10 将 J2、J3 固定到长连杆，两关节轴须同向。

## 6安装上臂到关节 1

材料：当前本体 1 套、上臂 1 套、外六角螺丝 M3×8 共 6 个、十字平头螺丝 M2×6 共 2 个

工具：开口扳手 5.5 mm、十字螺丝刀

将 J2 安装到 J1，步骤与「关节 1 安装到底座」相同。

关节 1 底部的 M2 螺丝较难安装，此阶段可先只安装顶部 M2 螺丝。

## 7组装前臂

材料：DM4310 关节（J4）1 个、elbow.lua 1 个、linkage.lua（短）1 个、内六角螺丝 M3×10 共 12 个、XT30(2+2) 线 2 根、导线若干、焊锡、热缩管

工具：电烙铁、内六角扳手

1. XT30 线插入 J4，导线经电机上方孔穿入 shell。
2. 4 条延长线插入短连杆导线孔。
3. 一端经 J4 法兰槽穿入 shell 至电机顶部；另一端经 elbow.lua 侧边方形孔穿出。
4. 焊接所有导线。
5. 用 M3×10 将 J4 与 elbow 固定到短连杆，注意两轴轴向关系。

## 8安装前臂到关节 3

材料：当前本体、前臂、外六角螺丝 M3×8 ×6、十字平头螺丝 M2×6 ×2

工具：开口扳手 5.5 mm、十字螺丝刀

将 elbow 安装到 J3，步骤同关节 1 安装到底座。

## 9安装关节 5 和关节 6

材料：DM4310 关节（J5、J6）2 个、外六角螺丝 M3×8 共 12 个、十字平头螺丝 M2×6 共 4 个

工具：开口扳手 5.5 mm、十字螺丝刀

1. 将 J5 安装到 J4，步骤同关节 1 安装到底座。
2. 将 J6 安装到 J5，步骤相同。

完成机械组装后，进行 CAN 总线菊花链连接、120Ω 终端电阻与 24V 供电。

## 10关节零点标定

机械组装完成后，使用 motor_gui.py 对各关节进行零点标定，零点姿态需与 URDF 模型一致。

安全警告 — 标定零点前必须失能电机：在设置零点、手动扳动关节对位时，务必先点击「失能电机」或切断 24V 供电。若电机处于使能状态，手动转动关节或发送设零/控制命令时，控制器可能突然输出力矩，导致飞车、猛冲或夹伤。正确顺序：失能 → 手动对位 → 确认零位 →（如需）设零/写参数 → 再使能测试。

python tools/motor_gui/motor_gui.py
1. 逐关节连接（修改电机 ID 1～6，电机类型 J2/J3 选 DM4340，其余选 DM-J4310-2EC）。
2. 失能电机（或断电），确认界面显示未使能后再进行下一步。
3. 在失能/断电状态下，将机械臂手动移动到 URDF 定义的零位姿态（可使用 A 型平键销 M3×3×6 辅助对齐，对照下方图示中的银色对齐标记）。
4. 零位对齐后，保持失能，如需软件设零再点击「设置零点」—— 注意：DM4310/4340 为双编码器电机，set_zero 命令在驱动中标注为对双编码器无效；实际标定以机械对齐为主，软件设零请参考 README 中的 calibrate_joint.jpg 图示与达妙调试助手说明。
5. 标定完成后再使能，小角度验证正反转：确认电机正转方向与 URDF 关节正方向（逆时针为 rad+）一致；若相反，在配置中将该关节 direction 改为 -1（见 关节旋转方向）。异常立即失能并断电。

关节零点标定

## 故障排查

现象 | 可能原因 | 处理办法
MoveIt / RViz 卡在启动界面；终端报 Failed to acquire lock in 20 seconds（spawner_mockway_group_controller） | 电机 CAN 连线或供电异常：总线未接通、CAN_H/L 接反/松动、24V 未上电、终端电阻缺失、CAN ID 冲突、USB-CAN 未透传到 WSL（/dev/ttyACM0 不可用）等，导致 ros2_control 无法完成硬件初始化，控制器 spawner 一直抢锁重试 | ① 断电后检查各电机 CAN 串联与 120Ω 终端电阻；② 确认 24V 供电与 USB-CAN 模块（921600 / CAN 1M）；③ 用 motor_gui 逐台验证 ID 与通信；④ WSL 下先执行 USB 透传并确认 ls /dev/ttyACM0；⑤ 仅验证 MoveIt 软件时：ros2 launch moveit_mockway_config demo.launch.py use_mock_hardware:=true
motor_gui 连接后无反馈 | 电机 ID / Master ID 不匹配；CAN 接线错误；未上电 | 用达妙助手 Read Param 核对 ID；检查 CAN_H/L；确认 24V 供电
多台电机同时连接时混乱 | 存在重复 CAN_ID | 逐台断开，单独用调试助手重新 Write Param
MoveIt 某关节无响应 | ros2_control.xacro 中 can_id 与电机不一致 | 对照本文 ID 表检查 xacro 与 dynamics_test.yaml
J3 方向相反 / 某关节补偿反力 | 物理安装与默认 dir 不一致；未按 URDF 正方向设置 direction | 在 motor_gui 中逐关节验证正转与 rad 正负（见关节旋转方向），修正 yaml 与 xacro 中的 direction / dir；勿随意改 CAN ID
补偿力矩过大/过小，或完整动力学模式抖动 | 两种模式共用倍率；full_dynamics_torque_scale 过大 | 分开设置 gravity_torque_scale 与 full_dynamics_torque_scale；称重修正 URDF
CAN 总线无数据 | 缺少 120Ω 终端电阻；波特率非 1M | 总线两端加 120Ω；确认适配器与电机均为 1 Mbps

### 快速 CAN 测试命令（Linux / SocketCAN）

# 使能 ID=1 的电机
cansend can0 001#FFFFFFFFFFFFFFFFFC

# 监听总线
candump can0

牧卫机器人 Mockway Robotics · 组装指南 HTML 版 · 基于仓库代码与 doc/组装指南.md 生成

相关文档：BOM.md · 组装指南.md · README.md

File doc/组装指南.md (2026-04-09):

# 组装指南

## 1 嵌入所有热熔螺母

工具：`电烙铁`

### M2

材料：`flange.lua`结构件 5个、`土八热熔螺母M2*3*3` 10个



### M3

材料：`shell.lua`结构件 6个、`tail.lua`结构件 1个、`base.lua`结构件 1个、`elbow.lua`结构件 1个、`土八热熔螺母M3*4*4` 60个

|  |  |  |  |
|:---:|:---:|:---:|:---:|
| shell | tail | base | elbow |

## 2 安装所有电机到shell

材料：`shell.lua`结构件 6个、DM4310电机 4个、DM4340电机 2个、`沉头十字螺丝M3*8` 36个

工具：`十字螺丝刀`



## 3 安装所有法兰到电机转子

材料：装完电机的shell 6个、`flange.lua`结构件 5个、`tail.lua`结构件 1个、`沉头十字螺丝M3*12` 36个

工具：`十字螺丝刀`



## 4 安装关节1到基座

材料：`base.lua`结构件 1个、DM4310关节 1个、`外六角螺丝M3*8` 6个、`十字平头螺丝M2*6` 2个

工具：`开口扳手5.5mm`、`十字螺丝刀`

1. 将`外六角螺丝M3*8`转入小部分到`base.lua`结构件的热熔螺母上
2. 法兰两侧的M2热熔螺母对准基座的M2通孔，沿圆弧槽转到法看大孔对准外六角螺丝头
3. 所有头都穿过关节法兰后，将螺丝转入法兰圆弧槽内
4. 将两个`十字平头螺丝M2*6`穿过基座M2通孔，固定在关节上
5. 使用`开口扳手5.5mm`将螺丝固定在基座上

## 5 组装上臂

材料：DM4340关节(J2 J3) 2个、`linkage.lua`(长) 1个、`内六角螺丝钉M3*10` 12个、`X30(2+2)线` 2个、导线若干、焊锡、热缩管或电工胶布

工具：`电烙铁`、`内六角扳手`

1. 将`X30(2+2)线`插入关节2后，将导线通过电机上方剩余的导线孔穿入shell内
2. 关节3同上
3. 将4条延长线插入`linkage.lua`(长)结构件的导线孔内
4. 将延长线的两端分别通过关节2和关节3的法兰槽通孔穿入shell内，到电机顶部
5. 焊接所有导线
6. 使用`内六角螺丝钉M3*10`分别将关节2和关节3固定到`linkage.lua`(长)结构件，注意两关节轴要同向

## 6 安装上臂到关节1

材料：当前本体 1个、上臂 1个、`外六角螺丝M3*8` 6个、`十字平头螺丝M2*6` 2个

工具：`开口扳手5.5mm`、`十字螺丝刀`

将关节2安装到关节1上，步骤与关节1安装到底座相同

注意：关节1底部的M2螺丝难安装，此时安装顶部的即可

## 7 组装前臂

材料：DM4310关节(J4) 1个、`elbow.lua` 1个、`linkage.lua`(短) 1个、`内六角螺丝钉M3*10` 12个、`X30(2+2)线` 2个、导线若干、焊锡、热缩管或电工胶布

工具：`电烙铁`、`内六角扳手`

1. 将`X30(2+2)线`插入关节4后，将导线通过电机上方剩余的导线孔穿入shell内
2. 将4条延长线插入`linkage.lua`(短)结构件的导线孔内
3. 将延长线的一端分别通过关节4的法兰槽通孔穿入shell内，到电机顶部，另一端通过`elbow.lua`结构件的侧边方形孔穿出
4. 焊接所有导线
5. 使用`内六角螺丝钉M3*10`分别将关节4和`elbow.lua`结构件固定到`linkage.lua`(短)结构件，注意两个轴向

## 8 安装前臂到关节3

材料：当前本体 1个、前臂 1个、`外六角螺丝M3*8` 6个、`十字平头螺丝M2*6` 2个

工具：`开口扳手5.5mm`、`十字螺丝刀`

将`elbow`安装到关节3上，步骤与关节1安装到底座相同

## 9 安装关节5和关节6

材料：当前本体 1个、DM4310关节(J5 J6) 2个、`外六角螺丝M3*8` 12个、`十字平头螺丝M2*6` 4个

工具：`开口扳手5.5mm`、`十字螺丝刀`

1. 将关节5安装到关节4上，步骤与关节1安装到底座相同
2. 将关节6安装到关节5上，步骤与关节1安装到底座相同

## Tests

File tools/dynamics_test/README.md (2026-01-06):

# Mockway Robot - Inverse Dynamics Testing

基于 Pinocchio 库实现的 Mockway 机器人动力学逆解测试工程。

## 概述

本测试工程使用 Pinocchio（一个高效的刚体动力学库）来计算 Mockway 机器人的逆向动力学。

**逆向动力学（Inverse Dynamics）**：给定关节的位置、速度和加速度，计算所需的关节力矩。

数学表达式：
```
τ = M(q)·a + C(q,v)·v + g(q)
```

其中：
- `τ`: 关节力矩
- `M(q)`: 质量矩阵（惯性矩阵）
- `C(q,v)`: 科里奥利和离心力矩阵
- `g(q)`: 重力项
- `q`: 关节位置
- `v`: 关节速度
- `a`: 关节加速度

## 功能特性

本测试程序实现了以下功能：

1. **静态配置测试**：计算多个静态姿态下的重力补偿力矩
2. **轨迹跟踪测试**：沿正弦轨迹计算所需力矩并可视化
3. **动力学分解测试**：验证 M、C、g 各项的正确性
4. **可视化输出**：生成位置、速度、加速度和力矩的时间曲线图

## 安装依赖

### 方法 1：使用 pip 安装

```bash
cd tools/dynamics_test
pip install -r requirements.txt
```

### 方法 2：使用 conda 安装

```bash
# 创建新环境（推荐）
conda create -n mockway_dynamics python=3.8
conda activate mockway_dynamics

# 安装 Pinocchio
conda install pinocchio -c conda-forge

# 安装其他依赖
pip install numpy matplotlib
```

### 依赖说明

- **pin** (Pinocchio >=3.0.0): 刚体动力学计算库
- **numpy** (>=1.20.0): 数值计算
- **matplotlib** (>=3.3.0): 数据可视化

## 使用方法

### 运行完整测试

```bash
cd tools/dynamics_test
python inverse_dynamics_test.py
```

这将运行所有三个测试：
1. 静态配置测试
2. 动力学分解测试
3. 轨迹跟踪测试（并生成可视化图表）

### 输出示例

```
============================================================
Mockway Robot - Inverse Dynamics Testing with Pinocchio
============================================================

Model loaded: mockway_description
Number of joints: 2
Joint names: ['joint1', 'joint2']

============================================================
TEST 1: Static Configurations (Zero Velocity & Acceleration)
============================================================

Zero position:
  Joint positions: [0. 0.] deg
  Required torques: [0. 0.] Nm
  Gravity torques:  [0. 0.] Nm

Joint1 = 45°:
  Joint positions: [45. 0.] deg
  Required torques: [0.123 0.456] Nm
  Gravity torques:  [0.123 0.456] Nm

...
```

## 代码结构

```
dynamics_test/
├── inverse_dynamics_test.py    # 主测试程序
├── requirements.txt            # Python 依赖
├── README.md                   # 本文档
└── trajectory_results.png      # 生成的可视化结果（运行后生成）
```

## 核心 API

### MockwayDynamics 类

```python
class MockwayDynamics:
    def __init__(self, urdf_path)
    def compute_inverse_dynamics(self, q, v, a) -> tau
    def compute_mass_matrix(self, q) -> M
    def compute_coriolis(self, q, v) -> c
    def compute_gravity(self, q) -> g
    def get_end_effector_pose(self, q) -> (position, orientation)
```

### 使用示例

```python
from inverse_dynamics_test import MockwayDynamics
import numpy as np

# 初始化
dynamics = MockwayDynamics("path/to/mockway_description.urdf")

# 定义关节状态
q = np.array([0.5, 0.3])      # 位置 [rad]
v = np.array([0.1, -0.2])     # 速度 [rad/s]
a = np.array([1.0, 0.5])      # 加速度 [rad/s²]

# 计算所需力矩
tau = dynamics.compute_inverse_dynamics(q, v, a)
print(f"Required torques: {tau} Nm")

# 分别计算各项
M = dynamics.compute_mass_matrix(q)
c = dynamics.compute_coriolis(q, v)
g = dynamics.compute_gravity(q)
```

## 测试说明

### Test 1: 静态配置测试

测试在不同关节位置下的静态平衡（零速度、零加速度）。在此情况下，所需力矩应等于重力补偿力矩。

### Test 2: 动力学分解测试

验证逆动力学的正确性，通过对比：
- RNEA 算法（递归牛顿-欧拉算法）的结果
- 手动计算 M·a + C·v + g 的结果

两者应该一致。

### Test 3: 轨迹跟踪测试

沿正弦轨迹运动，计算每个时刻所需的关节力矩，并生成可视化图表：
- 关节位置曲线
- 关节速度曲线
- 关节加速度曲线
- 所需关节力矩曲线

## 参考资料

### Pinocchio 文档
- 官方网站: https://stack-of-tasks.github.io/pinocchio/
- GitHub: https://github.com/stack-of-tasks/pinocchio
- 教程: https://gepettoweb.laas.fr/doc/stack-of-tasks/pinocchio/master/doxygen-html/

### 逆向动力学相关
- [Rigid Body Dynamics Algorithms](https://link.springer.com/book/10.1007/978-1-4899-7560-7) by Roy Featherstone
- [Modern Robotics](http://hades.mech.northwestern.edu/index.php/Modern_Robotics) by Kevin M. Lynch and Frank C. Park

## 常见问题

**Q: 为什么在静态配置下力矩不为零？**

A: 即使机器人静止，重力仍会产生力矩。逆动力学计算的是维持给定状态所需的力矩，包括重力补偿。

**Q: 如何修改测试轨迹？**

A: 在 `test_trajectory_tracking()` 函数中修改 `amplitude` 和 `frequency` 参数即可。

**Q: 可以用于其他机器人吗？**

A: 可以，只需将 URDF 文件路径改为你的机器人模型即可。确保 URDF 包含正确的惯性参数。

## 许可

本测试工程遵循项目整体许可协议。

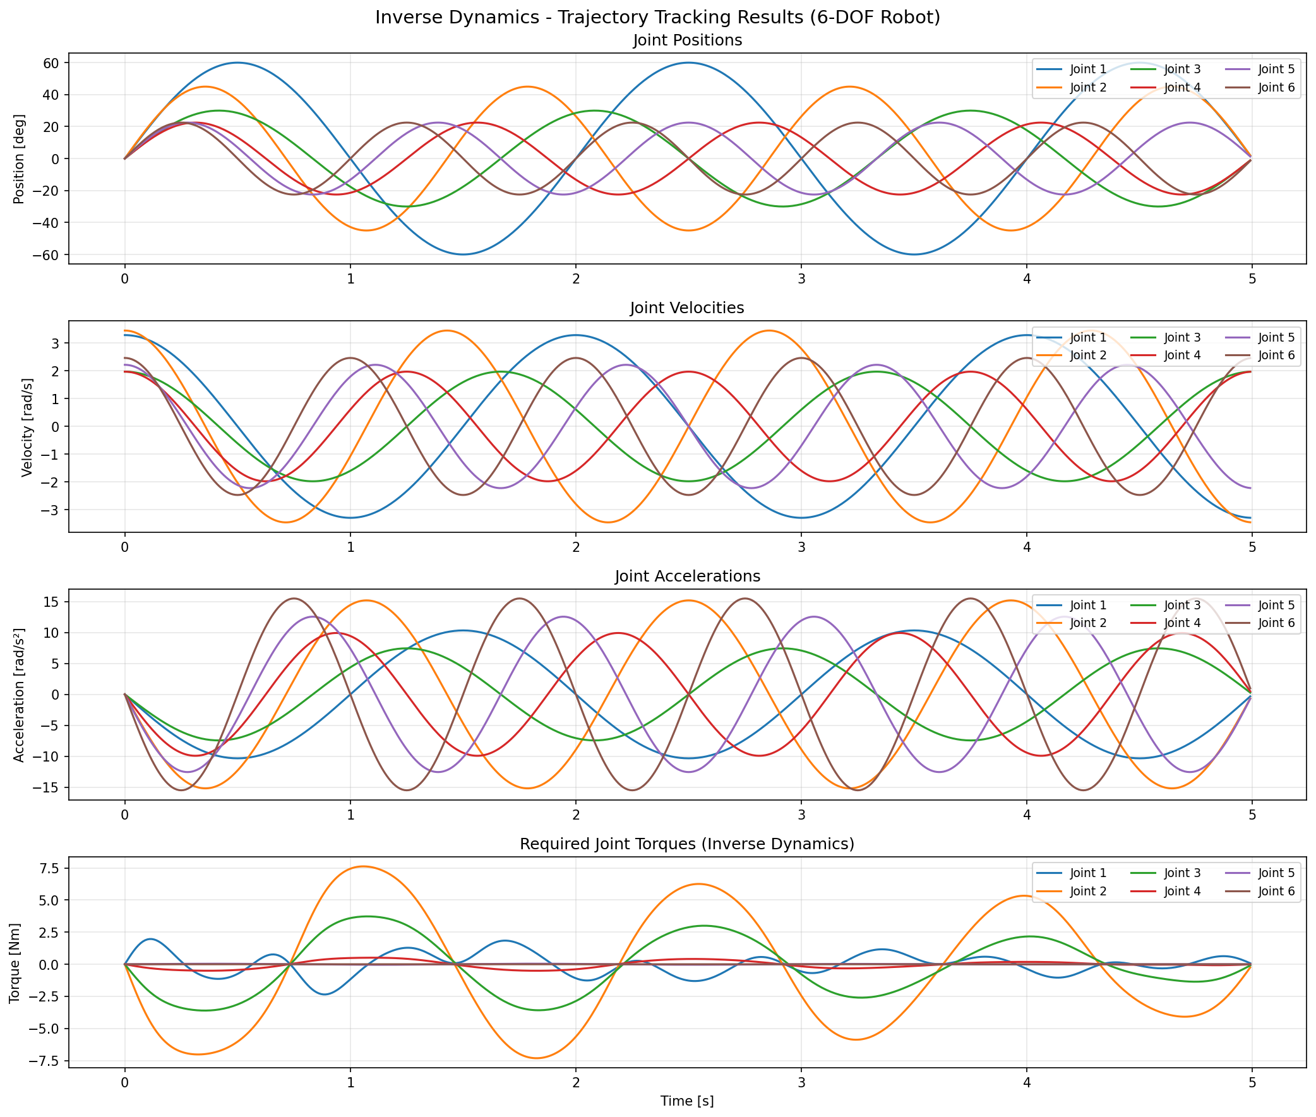
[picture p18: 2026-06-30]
tools/dynamics_test/trajectory_results.png

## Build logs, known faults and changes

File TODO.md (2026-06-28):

moveit WSL的ubuntu版本只有在运行完整的wsl安装程序后才能启动图形界面，否则卡死在启动界面。不知道为什么
先使用setup_wsl_moveit安装所有环境，然后在用launch_moveit_demo启动即可

每次启动moveit后，1轴非常快速的剧烈移动一下

目前步骤
1， 管理员启动setup_wsl_moveit选1全新安装
2， 重新挂载USB CAN
3，普通用户启动launch_moveit_demo

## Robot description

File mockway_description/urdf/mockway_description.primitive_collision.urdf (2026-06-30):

<?xml version="1.0"?>
<robot name="mockway_description">
<!-- 自动生成(请勿手改): tools/gen_macos_collision_urdf.py
     仅供 macOS(RoboStack) 使用 box 碰撞，规避 FCL 网格 BVH 在 Eigen5 下的崩溃。
     Linux/WSL 仍使用 mockway_description.urdf 的网格碰撞。 -->


  <link name="base_link">
    <inertial>
      <mass value="0.097"/>
      <origin xyz="-0.000 -0.000 0.014" rpy="0 0 0"/>
      <inertia ixx="0.000049" iyy="0.000049" izz="0.000080" ixy="-0.000000" ixz="0.000000" iyz="0.000000"/>
    </inertial>
    <visual>
      <origin xyz="0 0 0" rpy="0 0 0"/>
      <geometry>
        <mesh filename="package://mockway_description/meshes/base_link.stl"/>
      </geometry>
      <material name="">
        <color rgba="0.127 0.301 0.847 1.000"/>
      </material>
    </visual>
    <collision>
      <origin xyz="0 0 0.0169" rpy="0 0 0"/>
      <geometry>
        <box size="0.09 0.09 0.0338"/>
      </geometry>
    </collision>
  </link>

  <joint name="joint1" type="revolute">
    <parent link="base_link"/>
    <child link="link1"/>
    <origin xyz="0.000 0.000 0.064" rpy="0.000 -0.000 0.000"/>
    <axis xyz="0 0 1"/>
    <limit lower="-6.280" upper="6.280" effort="9.000" velocity="3.140"/>
  </joint>

  <link name="link1">
    <inertial>
      <mass value="0.378"/>
      <origin xyz="0.000 -0.003 -0.005" rpy="0 0 0"/>
      <inertia ixx="0.000195" iyy="0.000176" izz="0.000204" ixy="-0.000000" ixz="-0.000000" iyz="0.000005"/>
    </inertial>
    <visual>
      <origin xyz="0 0 0" rpy="0 0 0"/>
      <geometry>
        <mesh filename="package://mockway_description/meshes/link1.stl"/>
      </geometry>
      <material name="">
        <color rgba="0.231 0.162 1.000 1.000"/>
      </material>
    </visual>
    <collision>
      <origin xyz="0 -0.0046 0.0012" rpy="0 0 0"/>
      <geometry>
        <box size="0.0634 0.0726 0.0658"/>
      </geometry>
    </collision>
  </link>

  <joint name="joint2" type="revolute">
    <parent link="link1"/>
    <child link="link2"/>
    <origin xyz="0.000 0.000 0.000" rpy="1.571 -0.000 0.000"/>
    <axis xyz="0 0 1"/>
    <limit lower="-6.280" upper="6.280" effort="9.000" velocity="3.140"/>
  </joint>

  <link name="link2">
    <inertial>
      <mass value="0.568"/>
      <origin xyz="0.000 0.035 0.069" rpy="0 0 0"/>
      <inertia ixx="0.002661" iyy="0.000305" izz="0.002654" ixy="-0.000000" ixz="-0.000000" iyz="-0.000043"/>
    </inertial>
    <visual>
      <origin xyz="0 0 0" rpy="0 0 0"/>
      <geometry>
        <mesh filename="package://mockway_description/meshes/link2.stl"/>
      </geometry>
      <material name="">
        <color rgba="0.031 0.558 0.558 1.000"/>
      </material>
    </visual>
    <collision>
      <origin xyz="0 0.0952 0.0718" rpy="0 0 0"/>
      <geometry>
        <box size="0.0634 0.2538 0.0658"/>
      </geometry>
    </collision>
  </link>

  <joint name="joint3" type="revolute">
    <parent link="link2"/>
    <child link="link3"/>
    <origin xyz="0.000 0.190 0.000" rpy="0.000 -0.000 0.000"/>
    <axis xyz="0 0 1"/>
    <limit lower="-3.140" upper="3.140" effort="9.000" velocity="3.140"/>
  </joint>

  <link name="link3">
    <inertial>
      <mass value="0.488"/>
      <origin xyz="-0.000 0.131 0.006" rpy="0 0 0"/>
      <inertia ixx="0.001818" iyy="0.000257" izz="0.001814" ixy="0.000000" ixz="-0.000000" iyz="0.000079"/>
    </inertial>
    <visual>
      <origin xyz="0 0 0" rpy="0 0 0"/>
      <geometry>
        <mesh filename="package://mockway_description/meshes/link3.stl"/>
      </geometry>
      <material name="">
        <color rgba="1.000 0.212 0.080 1.000"/>
      </material>
    </visual>
    <collision>
      <origin xyz="0 0.0817 0.0034" rpy="0 0 0"/>
      <geometry>
        <box size="0.0634 0.2268 0.075"/>
      </geometry>
    </collision>
  </link>

  <joint name="joint4" type="revolute">
    <parent link="link3"/>
    <child link="link4"/>
    <origin xyz="0.000 0.163 0.000" rpy="0.000 -0.000 0.000"/>
    <axis xyz="0 0 1"/>
    <limit lower="-6.280" upper="6.280" effort="3.000" velocity="3.140"/>
  </joint>

  <link name="link4">
    <inertial>
      <mass value="0.378"/>
      <origin xyz="0.000 0.005 0.068" rpy="0 0 0"/>
      <inertia ixx="0.000195" iyy="0.000204" izz="0.000176" ixy="0.000000" ixz="-0.000000" iyz="-0.000005"/>
    </inertial>
    <visual>
      <origin xyz="0 0 0" rpy="0 0 0"/>
      <geometry>
        <mesh filename="package://mockway_description/meshes/link4.stl"/>
      </geometry>
      <material name="">
        <color rgba="0.701 0.162 0.672 1.000"/>
      </material>
    </visual>
    <collision>
      <origin xyz="0 -0.0012 0.066" rpy="0 0 0"/>
      <geometry>
        <box size="0.0634 0.0658 0.0726"/>
      </geometry>
    </collision>
  </link>

  <joint name="joint5" type="revolute">
    <parent link="link4"/>
    <child link="link5"/>
    <origin xyz="0.000 0.000 0.071" rpy="-1.571 0.000 0.000"/>
    <axis xyz="0 0 1"/>
    <limit lower="-6.280" upper="6.280" effort="3.000" velocity="3.140"/>
  </joint>

  <link name="link5">
    <inertial>
      <mass value="0.378"/>
      <origin xyz="-0.000 -0.005 0.068" rpy="0 0 0"/>
      <inertia ixx="0.000195" iyy="0.000204" izz="0.000176" ixy="0.000000" ixz="0.000000" iyz="0.000005"/>
    </inertial>
    <visual>
      <origin xyz="0 0 0" rpy="0 0 0"/>
      <geometry>
        <mesh filename="package://mockway_description/meshes/link5.stl"/>
      </geometry>
      <material name="">
        <color rgba="0.061 0.223 0.456 1.000"/>
      </material>
    </visual>
    <collision>
      <origin xyz="0 0.0012 0.066" rpy="0 0 0"/>
      <geometry>
        <box size="0.0634 0.0658 0.0726"/>
      </geometry>
    </collision>
  </link>

  <joint name="joint6" type="revolute">
    <parent link="link5"/>
    <child link="link6"/>
    <origin xyz="0.000 -0.039 0.071" rpy="1.571 -0.000 0.000"/>
    <axis xyz="0 0 1"/>
    <limit lower="-6.280" upper="6.280" effort="3.000" velocity="3.140"/>
  </joint>

  <link name="link6">
    <inertial>
      <mass value="0.016"/>
      <origin xyz="0.000 -0.000 -0.004" rpy="0 0 0"/>
      <inertia ixx="0.000003" iyy="0.000003" izz="0.000006" ixy="0.000000" ixz="0.000000" iyz="0.000000"/>
    </inertial>
    <visual>
      <origin xyz="0 0 0" rpy="0 0 0"/>
      <geometry>
        <mesh filename="package://mockway_description/meshes/link6.stl"/>
      </geometry>
      <material name="">
        <color rgba="0.527 0.527 0.527 1.000"/>
      </material>
    </visual>
    <collision>
      <origin xyz="0 0 -0.00525" rpy="0 0 0"/>
      <geometry>
        <box size="0.0584 0.0584 0.0095"/>
      </geometry>
    </collision>
  </link>

</robot>

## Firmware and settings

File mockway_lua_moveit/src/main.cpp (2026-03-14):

/**
 * main.cpp — lua_moveit_node 入口
 *
 * 节点参数：
 *   planning_group (string, default "mockway_group")
 *   ee_frame       (string, default "link6")
 *   base_frame     (string, default "base_link")
 *
 * 执行源优先级：
 *   1. 命令行位置参数（首个非 --ros-args 参数，视为脚本路径）
 *   2. ROS 参数 script_path（Lua 脚本文件路径）
 *   3. ROS 参数 script_code（Lua 代码字符串）
 */

#include "mockway_lua_moveit/lua_moveit_node.hpp"
#include "mockway_lua_moveit/http_server.hpp"

#include <rclcpp/executors/single_threaded_executor.hpp>
#include <chrono>
#include <thread>

int main(int argc, char** argv)
{
  rclcpp::init(argc, argv);

  auto node = std::make_shared<LuaMoveItNode>();

  // 后台 executor：MoveGroupInterface / Service 调用需要 spin
  rclcpp::executors::SingleThreadedExecutor executor;
  executor.add_node(node);
  std::thread spin_thread([&executor]() { executor.spin(); });

  // HTTP 服务器（端口由 ROS 参数 http_port 控制，默认 8080）
  if (!node->has_parameter("http_port"))
    node->declare_parameter("http_port", 8080);
  const int http_port = node->get_parameter("http_port").as_int();

  HttpServer http_server(node, http_port);
  http_server.start();

  // 获取执行源
  std::string script_path;
  if (argc >= 2 && argv[1][0] != '-') {
    script_path = argv[1];
  } else {
    if (!node->has_parameter("script_path"))
      node->declare_parameter("script_path", std::string(""));
    script_path = node->get_parameter("script_path").as_string();
  }

  if (!node->has_parameter("script_code"))
    node->declare_parameter("script_code", std::string(""));
  std::string script_code = node->get_parameter("script_code").as_string();

  int ret = 0;
  if (!script_path.empty()) {
    ret = node->run_script(script_path);
  } else if (!script_code.empty()) {
    ret = node->run_string(script_code);
  } else {
    // 未指定脚本 — HTTP 服务器模式：保持运行直到 Ctrl+C
    RCLCPP_INFO(node->get_logger(),
      "HTTP 服务器模式（端口 %d）：未指定脚本，等待前端请求...", http_port);
    while (rclcpp::ok()) {
      std::this_thread::sleep_for(std::chrono::milliseconds(200));
    }
  }

  http_server.stop();
  executor.cancel();
  spin_thread.join();
  rclcpp::shutdown();
  return ret;
}

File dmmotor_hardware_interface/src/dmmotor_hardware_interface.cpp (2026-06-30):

#ifndef DAMIAO_HARDWARE_INTERFACE_HPP
#define DAMIAO_HARDWARE_INTERFACE_HPP

#include <memory>
#include <string>
#include <vector>
#include <chrono>
#include <thread>
#include <algorithm>
#include <sstream>
#include <iomanip>

#include "hardware_interface/handle.hpp"
#include "hardware_interface/hardware_info.hpp"
#include "hardware_interface/system_interface.hpp"
#include "hardware_interface/types/hardware_interface_return_values.hpp"
#include "hardware_interface/types/hardware_interface_type_values.hpp"
#include "rclcpp/macros.hpp"
#include "rclcpp/rclcpp.hpp"

// CAN通信相关头文件
#include <unistd.h>
#include <cstring>
#include <cstdint>
#include <cerrno>
#include <fcntl.h>     // O_NONBLOCK 定义在此
#include <termios.h>   // 串口配置（USB-CAN，POSIX：Linux/macOS 通用）
#include <sys/ioctl.h> // ioctl（SocketCAN 取接口号 / macOS 设置波特率）

#if defined(__linux__)
  // Linux/WSL：使用内核 SocketCAN（与原行为完全一致）
  #include <linux/can.h>
  #include <linux/can/raw.h>
  #include <sys/socket.h>
  #include <net/if.h>
  #define DMMOTOR_HAS_SOCKETCAN 1
#else
  // 非 Linux（如 macOS）：内核无 SocketCAN，仅支持 USB-CAN 串口路径。
  // 提供一个可移植的 can_frame 定义，使其余代码无需改动即可编译。
  #ifndef CAN_EFF_FLAG
    #define CAN_EFF_FLAG 0x80000000U
  #endif
  struct can_frame {
    uint32_t can_id;   // 帧 ID（兼容标准/扩展帧 + CAN_EFF_FLAG）
    uint8_t  can_dlc;  // 数据长度
    uint8_t  data[8];  // 数据
  };
  #define DMMOTOR_HAS_SOCKETCAN 0
  #if defined(__APPLE__)
    #include <IOKit/serial/ioss.h>  // IOSSIOSPEED：设置任意（非标准）串口波特率
  #endif
#endif

namespace dmmotor_hardware_interface
{

// CAN接口类型枚举
enum CanType
{
  SOCKET_CAN,   // Linux SocketCAN
  USB_CAN       // USB-CAN 适配器（达妙 / 维特）
};

enum UsbCanAdapter
{
  USB_CAN_DAMIAO,     // 达妙官方 USB-CAN（0x55 0xAA 帧）
  USB_CAN_WITMOTION,  // 维特 USB-CAN（AT 指令）
  USB_CAN_AUTO        // 打开串口后自动检测
};

class DMMototHardwareInterface : public hardware_interface::SystemInterface
{
public:
  RCLCPP_SHARED_PTR_DEFINITIONS(DMMototHardwareInterface)

  hardware_interface::CallbackReturn on_init(const hardware_interface::HardwareInfo & info) override;
  
  hardware_interface::CallbackReturn on_configure(const rclcpp_lifecycle::State & previous_state) override;
  
  std::vector<hardware_interface::StateInterface> export_state_interfaces() override;
  
  std::vector<hardware_interface::CommandInterface> export_command_interfaces() override;
  
  hardware_interface::CallbackReturn on_activate(const rclcpp_lifecycle::State & previous_state) override;
  
  hardware_interface::CallbackReturn on_deactivate(const rclcpp_lifecycle::State & previous_state) override;
  
  hardware_interface::return_type read(const rclcpp::Time & time, const rclcpp::Duration & period) override;
  
  hardware_interface::return_type write(const rclcpp::Time & time, const rclcpp::Duration & period) override;
  
  void print_hardware_info(const hardware_interface::HardwareInfo& info, rclcpp::Logger logger);

private:
  enum DM_Motor_Type
  {
    DM4310,
    DM4310_48V,
    DM4340,
    DM4340_48V,
    DM6006,
    DM8006,
    DM8009,
    DM10010L,
    DM10010,
    DMH3510,
    DMH6215,
    DMG6220,
    Num_Of_Motor
  };
  typedef struct
  {
    float Q_MAX;   // 位置范围 (rad)
    float DQ_MAX;  // 速度范围 (rad/s)
    float TAU_MAX; // 力矩范围 (Nm)
  } Limit_param;

  // 电机PMAX DQMAX TAUMAX参数
  Limit_param limit_param[Num_Of_Motor] =
      {
          {12.5, 30, 10},  // DM4310
          {12.5, 50, 10},  // DM4310_48V
          {12.5, 8, 28},   // DM4340
          {12.5, 10, 28},  // DM4340_48V
          {12.5, 45, 20},  // DM6006
          {12.5, 45, 40},  // DM8006
          {12.5, 45, 54},  // DM8009
          {12.5, 25, 200}, // DM10010L
          {12.5, 20, 200}, // DM10010
          {12.5, 280, 1},  // DMH3510
          {12.5, 45, 10},  // DMH6215
          {12.5, 45, 10}   // DMG6220
      };
  // 达妙电机MIT模式相关结构体
  struct DamiaoMotor {
    uint32_t can_id;
    double position;
    double velocity;
    double effort;
    double cmd_position;
    double cmd_velocity;
    double cmd_effort;
    double kp;
    double kd;
    double dir;
    bool is_simulated;  // 是否为仿真电机
    bool position_valid{false};  // 是否已读到有效反馈位置
    DM_Motor_Type type;
    Limit_param limit_param{};
  };

  // CAN通信相关
  CanType can_type_{SOCKET_CAN};  // CAN接口类型，默认SocketCAN
  UsbCanAdapter usb_can_adapter_{USB_CAN_DAMIAO};
  int can_socket_{-1};            // SocketCAN socket文件描述符
  int serial_fd_{-1};             // USB-CAN串口文件描述符
  int serial_baudrate_{921600};   // USB-CAN串口波特率
  std::string can_interface_;     // CAN接口名称（can0）或串口设备路径（/dev/ttyUSB0）
  std::vector<uint8_t> usb_can_rx_buffer_;  // USB-CAN接收缓冲区
  bool is_sim_hardware{true};     // 是否为仿真硬件接口，遇到非仿真关节时设置false，默认true
  bool hold_safe_mode_{false};    // 激活后短时零增益保持，防止控制器命令突变
  int hold_cycles_remaining_{0};

  // 电机列表
  std::vector<DamiaoMotor> motors_;
  
  // MIT模式控制参数
  static constexpr double KP_MIN = 0.0;    // Kp范围
  static constexpr double KP_MAX = 500.0;
  static constexpr double KD_MIN = 0.0;    // Kd范围
  static constexpr double KD_MAX = 5.0;
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

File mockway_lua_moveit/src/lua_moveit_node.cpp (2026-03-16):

/**
 * lua_moveit_node.cpp
 *
 * LuaMoveItNode 类实现。
 * 将 MoveIt 和 MoveIt Servo 封装为全局 Lua API（驼峰命名，无 robot 表），支持：
 *   - 关节/笛卡尔手动点动 (Servo)
 *   - 点到点规划执行 (PTP: MoveJ / MovePose)
 *   - 直线运动 (MoveL / MoveLRel / MoveLRelTool)
 *
 * Lua 全局 API 速查：
 *   ServoMode(mode)                           切换 Servo 模式 "joint_jog"|"twist"
 *   ServoJoint(idx, vel)                      单关节点动 deg/s
 *   ServoJoints({v1..v6})                     六轴点动 deg/s
 *   ServoCart(vx,vy,vz,rx,ry,rz[,frame])      笛卡尔点动 mm/s, deg/s
 *   ServoStop()                               停止点动
 *   MoveNamed(name)                           PTP → SRDF 命名状态
 *   MoveJ({j1..j6})                           PTP → 关节角 deg
 *   MovePose(x,y,z,roll,pitch,yaw)            PTP → 末端位姿 mm, deg
 *   MoveL(x,y,z,roll,pitch,yaw[,step])        直线 → 绝对位姿 mm, deg
 *   MoveLRel(dx,dy,dz,drx,dry,drz[,step])     直线 → 相对基坐标系增量 mm, deg
 *   MoveLRelTool(dx,dy,dz,drx,dry,drz[,step]) 直线 → 相对工具坐标系增量 mm, deg
 *   SetVelScale(f)                            速度比例 [0.01, 1.0]
 *   SetAccScale(f)                            加速度比例 [0.01, 1.0]
 *   SetPlanTime(t)                            规划超时 s
 *   SetPlanner(id)                            切换规划器
 *   GetJoints()  → {j1..j6} deg              获取关节角
 *   GetPose()    → {x,y,z,roll,pitch,yaw}     获取末端位姿 mm, deg
 *   Sleep(ms)                                 暂停 ms 毫秒
 *   Log(msg) / LogWarn(msg) / LogError(msg)   ROS 日志
 *   Ok()                                      节点运行中返回 true
 *   DegRad(d) / RadDeg(r)                     角度转换
 */

#include "mockway_lua_moveit/lua_moveit_node.hpp"

#include <moveit/planning_scene_interface/planning_scene_interface.hpp>
#include <geometry_msgs/msg/pose.hpp>
#include <geometry_msgs/msg/transform_stamped.hpp>
#include <tf2_geometry_msgs/tf2_geometry_msgs.hpp>
#include <tf2_eigen/tf2_eigen.hpp>
#include <tf2/exceptions.h>
#include <Eigen/Geometry>

#include <chrono>
#include <filesystem>
#include <future>
#include <sstream>
#include <thread>

using namespace std::chrono_literals;

// ─────────────────────────── 常量 ────────────────────────────────────────────
namespace defaults {
  const std::string PLANNING_GROUP = "mockway_group";
  const std::string EE_FRAME       = "link6";
  const std::string BASE_FRAME     = "base_link";
  const std::string TWIST_TOPIC    = "/servo_node/delta_twist_cmds";
  const std::string JOINT_TOPIC    = "/servo_node/delta_joint_cmds";
  const std::vector<std::string> JOINT_NAMES = {
    "joint1","joint2","joint3","joint4","joint5","joint6"
  };
}

// ─────────────────────────── 构造 ────────────────────────────────────────────
LuaMoveItNode::LuaMoveItNode()
: Node("lua_moveit_node",
       rclcpp::NodeOptions().automatically_declare_parameters_from_overrides(true))
{
  planning_group_ = declare_or_get("planning_group", defaults::PLANNING_GROUP);
  ee_frame_       = declare_or_get("ee_frame",       defaults::EE_FRAME);
  base_frame_     = declare_or_get("base_frame",     defaults::BASE_FRAME);

  twist_pub_ = create_publisher<geometry_msgs::msg::TwistStamped>(
    defaults::TWIST_TOPIC, rclcpp::QoS(10));
  joint_pub_ = create_publisher<control_msgs::msg::JointJog>(
    defaults::JOINT_TOPIC, rclcpp::QoS(10));

  servo_mode_client_ = create_client<moveit_msgs::srv::ServoCommandType>(
    "/servo_node/switch_command_type");

  // ── 订阅关节状态 ──────────────────────────────────────────────────────────
  joint_state_sub_ = create_subscription<sensor_msgs::msg::JointState>(
    "/joint_states", rclcpp::SensorDataQoS(),
    [this](const sensor_msgs::msg::JointState::SharedPtr msg) {
      std::lock_guard<std::mutex> lk(joint_cache_mutex_);
      cached_joint_names_     = msg->name;
      cached_joint_positions_ = msg->position;
    });

  // ── TF2 缓冲区（用于末端位姿查询） ──────────────────────────────────────
  tf_buffer_   = std::make_shared<tf2_ros::Buffer>(get_clock());
  tf_listener_ = std::make_shared<tf2_ros::TransformListener>(*tf_buffer_, this);

  RCLCPP_INFO(get_logger(), "LuaMoveItNode 初始化完成，planning_group=%s",
              planning_group_.c_str());
}

// ─────────────────────────── 公开方法 ────────────────────────────────────────
bool LuaMoveItNode::init_move_group()
{
  std::lock_guard<std::mutex> lk(mg_mutex_);
  if (move_group_) return true;
  if (mg_failed_)  return false;

  try {
    move_group_ = std::make_shared<moveit::planning_interface::MoveGroupInterface>(
      shared_from_this(), planning_group_);
    move_group_->setMaxVelocityScalingFactor(0.3);
    move_group_->setMaxAccelerationScalingFactor(0.1);
    move_group_->setPlanningTime(5.0);
    RCLCPP_INFO(get_logger(), "MoveGroupInterface 就绪，规划参考系: %s",
                move_group_->getPlanningFrame().c_str());
    return true;
  } catch (const std::exception& e) {
    RCLCPP_ERROR(get_logger(),
      "MoveGroupInterface 初始化失败（move_group 未运行？）: %s", e.what());
    move_group_ = nullptr;
    mg_failed_  = true;
    return false;
  }
}

int LuaMoveItNode::run_script(const std::string& script_path)
{
  if (!std::filesystem::exists(script_path)) {
    RCLCPP_ERROR(get_logger(), "Lua 脚本不存在: %s", script_path.c_str());
    return -1;
  }

  std::lock_guard<std::mutex> lua_lk(lua_mutex_);
  setup_lua_api();

  std::filesystem::path p(script_path);
  std::string dir = p.parent_path().string();
  lua_.script("package.path = package.path .. ';' .. '" + dir + "/?.lua'");

  RCLCPP_INFO(get_logger(), "执行 Lua 脚本: %s", script_path.c_str());
  try {
    lua_.script_file(script_path);
  } catch (const sol::error& e) {
    RCLCPP_ERROR(get_logger(), "Lua 错误: %s", e.what());
    return -1;
  }
  return 0;
}

int LuaMoveItNode::run_string(const std::string& code)
{
  if (code.empty()) {
    RCLCPP_ERROR(get_logger(), "Lua 代码字符串为空");
    return -1;
  }

  std::lock_guard<std::mutex> lua_lk(lua_mutex_);
  setup_lua_api();

  RCLCPP_INFO(get_logger(), "执行 Lua 字符串（%zu 字节）", code.size());
  try {
    lua_.script(code);
  } catch (const sol::error& e) {
    RCLCPP_ERROR(get_logger(), "Lua 错误: %s", e.what());
    return -1;
  }
  return 0;
}
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

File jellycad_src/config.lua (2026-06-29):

--[[
Copyright (c) 2025. Li Jianbin. All rights reserved.
MIT License
JellyCAD version v0.3.10
Mockway Structure Config File
--]]
local config = {}
-- 装配
config.generate_step_file = true                                        -- true 运行combine.lua时生成所有零件的完整STEP文件，用于3D打印
-- 通用
config.r_motor = 57 / 2                                                  -- 电机直径57
config.r_motor_flank = 35 / 2                                            -- 电机法兰半径
config.r_screw_distribut = 50 / 2                                        -- 电机外壳螺丝分布半径
config.r_screw_motor_flank = 27 / 2                                      -- 电机法兰螺丝分布半径
config.h_motor_convex = 1                                                -- 电机凸台高度
config.thickness = 3                                                     -- 壳壁厚3
config.interspace = 0.2                                                  -- 电机壁与壳内壁的空隙0.2
config.r_outer = config.r_motor + config.interspace + config.thickness   -- 外壁半径
config.h_flank = 4                                                       -- 法兰高度(凹台高度)
config.t_flank_groove = 2                                                -- 法兰凹台壁厚
config.r_flank_groove = config.r_outer - config.t_flank_groove           -- 法兰凹台内壁半径
config.r_m2_hole = 1 + 0.1                                               -- M2螺丝通孔半径
config.r_m2d3_nut = 1.5 - 0.2                                            -- M2D3热熔螺母半径
config.r_m3d4_nut = 2 - 0.1                                              -- M3D4热熔螺母半径
config.r_m3_hole = 1.5 + 0.1                                             -- M3通孔半径
config.r_m3_head = 3                                                     -- M3平头空间半径
config.r_m2_tapping = 1.6 / 2                                            -- M2自攻螺丝孔
config.r_calib_slot = 1.7                                                -- 标定槽半径
config.h_calib_slot = 1                                                  -- 标定槽深度
config.r_flank = config.r_outer - config.t_flank_groove - 0.5            -- 法兰半径，预留0.5空间转动
config.r_flank_screw_head = 3.3                                          -- 法兰螺丝头通孔，用于通过M3外六角螺丝头
-- config.r_flank_screw_pos = config.r_flank - config.r_flank_screw_head - 2 -- 法兰螺丝位置半径
config.r_flank_screw_pos = config.r_screw_distribut                      -- 法兰螺丝位置半径
-- 基座
config.r_base_down = 45                                                  -- 基座下部半径
config.h_base_down = 8                                                   -- 基座下部高度
config.h_base_up = 16.6 + config.h_flank                                 -- 基座上部高度
config.h_base = config.h_base_down + config.h_base_up                    -- 基座总高度
config.r1_ellip = config.h_base_up                                       -- 切椭圆的半长轴
config.r2_ellip = config.r_base_down - config.r_outer                    -- 切椭圆的半短轴
config.z_base_m2_hole = config.h_base - config.h_flank / 2               -- 法兰侧边螺丝孔Z位置
config.r_m4_hole = 2.1                                                   -- 底座M4固定螺丝孔
config.r_m4_head = 4                                                     -- 底座M4固定螺丝头半径
config.r_base_vert_hole = 16                                             -- 竖直线孔半径
config.r_base_horiz_hole = 4                                             -- 水平线孔半径
config.z_base_horiz_hole = config.h_base_down + config.r_base_horiz_hole -- 水平线孔Z位置
config.r_base_screw_pos = 40                                             -- 底座螺丝位置半径
-- 外壳
config.r_shell_outer = config.r_outer                                    -- 外壳外壁半径
config.r_shell_inner = config.r_shell_outer - config.thickness           -- 外壳内壁半径
config.h_shell = 2 * config.r_outer                                      -- 外壳高度等于直径
config.r_shell_flank_hole = config.r_motor_flank + 1                     -- 外壳法兰孔半径，预留1的间隙
config.r_wire_hole = 12.5                                                -- 圆形通线孔半径
config.w_wire_solt = 2.4 * 2                                             -- 方形通线槽深度
config.l_wire_solt = 10                                                  -- 方形通线槽长度
config.w_can_plug = 16                                                   -- CAN插口宽度
config.w_ttl_plug = 10                                                   -- TTL插口宽度
config.h_plug = 17                                                       -- 插口高度
config.z_plug = config.thickness + 37                                    -- 插口底部Z位置
config.z_plug_top = config.z_plug + config.h_plug                        -- 插口顶部Z位置
-- 法兰
config.deg_slot = 18                                                     -- 螺丝槽角度
config.h_flank_reserve = 3.2;                                            -- 法兰预计抽空高度
-- 法兰颈部高度
config.h_flank_nick = (config.thickness - config.h_motor_convex) + config.h_flank_reserve;
config.h_flank_sum = config.h_flank_nick + config.h_flank; -- 法兰总高度
config.r_flank_outer = config.r_flank_groove - 0.5;        -- 法兰外壁半径，预留1mm空间转动
config.r_flank_inner = config.r_motor_flank;               -- 法兰本体半径
-- 连杆
config.r_arm_out = config.r_flank_screw_pos - 3.5 - 1;     -- 臂外径，预留螺母位，再额外预留1mm空间
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

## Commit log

2025-12-25 增加底座机械结构脚本
2025-12-25 取消无用的水平线孔，增加竖直的中心通孔减少材料
2025-12-26 增加注释，更新License
2025-12-26 增加模组外壳
2025-12-27 壳的插头孔高度可以缩小
2025-12-31 新增连杆模型的Lua脚本
2025-12-31 默认不导出和不显示，增加装配文件
2026-01-01 feat: add graphical user interface for DM-J4310-2EC motor control
    - Implemented a Tkinter-based GUI for controlling the DM-J4310-2EC motor via WitMotion USB-CAN adapter.
    - Added connection configuration, motor parameter settings, and control functionalities.
    - Included trapezoidal motion control logic for smooth acceleration and deceleration.
    - Integrated real-time status updates for motor position, velocity, torque, and error states.
    - Enabled user interaction through buttons for enabling/disabling the motor and controlling movement.
    [dm_motor_driver.py, motor_gui.py]
2026-01-04 feat: add README and requirements for DM-J4310-2EC motor control GUI
2026-01-04 更正窗口大小
2026-01-05 完善电机控制功能
2026-01-05 使能状态使用反馈数据
2026-01-05 增加清除错误指令帧
2026-01-05 更改架构，要求：1.串口连接后，发送清除错误控制，至少接收到一次反馈帧才可以进行下一步 操作，更新一次命令位置；2.上一部完成后启动插补线程，插补周期一直发送MIT控制帧保证能一直获取电机状态；3.电机使能前， 以反馈位置更新命令位置；4.电机使能后，命令位置、速度使用计算值
2026-01-05 电机控制操作不需要阻塞
2026-01-05 装配-增加两种电机
2026-01-05 优化位置和力矩控制区的布局，使其更紧凑
2026-01-05 修复力矩模式控制后，命令位置没有更新的问题
2026-01-05 将电机参数内的Kp、Kd、最大速度和最大加速度放到位置控制中
2026-01-06 1.增加电机质量;2.取消基座圆角,会影响装备显示(OCCT的BUG?)3.增加坐标系为导出URDF做准备
2026-01-06 装配-整理代码，导出ros2，需要精简基座等模型的复杂度(OCCT的bug?)
2026-01-06 修正大臂指令
2026-01-06 增加ROS2机器人描述文件
    [base_link.stl, link1.stl, link2.stl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]
2026-01-06 增加动力学测试代码
2026-01-07 增加末端法兰
2026-01-07 模型-整理电机壳，改为函数形式，并增加简化版
2026-01-07 增加实时力矩补偿控制系统的配置加载功能，支持动态电机配置和命令行参数覆盖
2026-01-07 增加加速度估计的低通滤波功能，优化全动态补偿模式中的加速度计算
2026-01-07 力矩补偿中减小阻尼kd值
2026-01-07 增加加速度信息显示
2026-01-08 取消加速度显示
2026-01-08 取消加速度信息的显示
2026-01-08 整理装配代码
2026-01-08 更新文件头部版权信息
2026-01-08 模型elbow函数化
2026-01-08 URDF增加关节3和前臂连杆
2026-01-08 修复上臂与前臂反了的问题
2026-01-09 增加电机旋转方向配置，更新相关控制逻辑
2026-01-09 测试示例-增加关节3电机
2026-01-11 末端法兰-函数化处理
2026-01-11 装配-加入末端法兰
2026-01-11 完成整个装配模型的URDF导出
2026-01-11 更新URDF，完成所有关节和连杆生成
    [link4.stl, link5.stl, link6.stl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]
2026-01-11 更新JellyCAD版本至v0.3.10，添加版权信息至多个模型文件
2026-01-12 增加BOM，更新视频地址
2026-01-12 更新说明文档
2026-01-12 obsidian内容不加入仓库
2026-01-13 新增配置Moveit2的步骤和解决方案文档
2026-01-14 增加moveit的ros包
    [joint_limits.yaml, mockway_description.ros2_control.xacro, mockway_description.urdf.xacro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]
2026-01-14 Add DM Motor Hardware Interface for ROS2 Control
    - Implemented a hardware interface for DM motors (DM-J4310-2EC and DM4340) using SocketCAN.
    - Created README.md with detailed instructions on features, motor configuration, prerequisites, building, usage, and troubleshooting.
    - Added example hardware configuration in YAML format.
    - Defined the hardware interface in XML format for plugin registration.
    - Developed the core functionality in C++ including CAN communication, motor control, and state management.
    - Updated mockway_description.ros2_control.xacro to integrate the new hardware interface and configure joints with motor parameters.
    [dmmotor_hardware_interface.xml, hardware_config_example.yaml, mockway_description.ros2_control.xacro]
2026-01-14 Refactor control parameters to support per-joint gains in DM Motor Hardware Interface
    [mockway_description.ros2_control.xacro]
2026-01-15 ros2_control-增加命令速度
    [ros2_controllers.yaml]
2026-01-15 硬件接口-兼容USB-CAN模块设备
    [mockway_description.ros2_control.xacro]
2026-01-15 目标容差配置 - 解决电机编码器误差导致的超时问题
    [mockway_description.ros2_control.xacro, ros2_controllers.yaml]
2026-01-15 增加机器人位置-准备位置
2026-01-16 模型-lid-增加logo
2026-01-16 调整logo位置
2026-01-18 Add CAN device information to README
    Added information about CAN device and its module.
2026-01-19 更新BOM
2026-01-20 Add 3D printing model link and image to README
2026-01-21 Remove redundant video link from README and clarify CAN device settings
2026-01-26 Add safety precautions and guidelines for torque mode operation in README
2026-01-26 Update joint limits and controller configurations to enhance performance and flexibility
    [joint_limits.yaml, mockway_description.ros2_control.xacro, ros2_controllers.yaml]
2026-01-27 Add keyboard control scripts for joint jogging, pose manipulation, and Cartesian movement
2026-01-28 Update ArUco tracking launch file for Gazebo Harmonic and add SDF world file
    [aruco_tracking.sdf]
2026-01-28 Add ArUco servo follower and update launch files for Gazebo simulation
    - Introduced aruco_servo_follower.py to convert ArUco marker pose to MoveIt Servo twist commands.
    - Added aruco_servo_sim.launch.py to launch Gazebo with ArUco tracking.
    - Updated CMakeLists.txt to include new scripts and directories.
    - Created gz_ros2_control.yaml for ros2_control configuration.
    - Enhanced aruco_tracker.py for compatibility with both old and new OpenCV ArUco APIs.
    - Added mockway_gazebo.urdf.xacro for robot description and control.
    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
    [aruco_tracking.sdf, gz_ros2_control.yaml, mockway_gazebo.urdf.xacro]
2026-02-02 模型-增加相机固定座
2026-02-03 更新 BOM.md 增加电机相关螺丝 感谢B站用户：我信了取个名字这么难 提醒
2026-02-04 更新接线拓扑图
2026-02-15 更新README
2026-02-27 删除servo的gazebo仿真及aruco标签跟踪
    [aruco_tracking.sdf, gz_ros2_control.yaml, mockway_gazebo.urdf.xacro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]
2026-03-12 修复script_path参数重复定义
2026-03-12 增强 init_move_group 函数，添加初始化失败处理并返回状态
2026-03-12 新增 servo_with_moveit.launch.py 启动文件，集成 MoveIt 和 MoveIt Servo，支持 RViz 配置
2026-03-12 修复参数命名冲突，将 use_rviz 更改为 with_rviz，以避免与 demo.launch.py 内部同名参数冲突
2026-03-12 增加lua接口的README
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2026-03-14 增加use_mock_hardware参数，用于仿真测试
    [mockway_description.ros2_control.xacro, mockway_description.urdf.xacro]
2026-03-14 增加UI
    [mockway_description.urdf]
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2026-03-14 /api/joints SSE 流现在完全由 topic 订阅缓存 + TF 驱动，不会阻塞 move_group
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2026-03-16 修复nlohmann-json库安装问题
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2026-03-17 设置消息持续时间
    [servo_config.yaml]
2026-03-18 修复npm build警告
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2026-03-18 调整servo配置
    [ros2_controllers.yaml, servo_config.yaml]
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2026-06-28 可以启动了
    [mockway_description.ros2_control.xacro, mockway_description.urdf.xacro]
2026-06-28 默认接真机运行
    [mockway_description.urdf.xacro]
2026-06-28 Revert "合并"
    This reverts commit a1aeb4582fa5345d9bf2288f468e858f91ae3a0b.
2026-06-28 Reapply "合并"
    This reverts commit 410bf6072a15f8ffb74453d76e4408ed129a4803.
2026-06-28 Revert "Reapply "合并""
    This reverts commit 5a6e39256b815369eaf66ccde0bf2bf6937f9d2a.
2026-06-28 修复moveit指令增加达妙usb can指令
    [mockway_description.ros2_control.xacro]
2026-06-28 目前问题
2026-06-28 尝试修复moveit启动后1轴突跳
    [ros2_controllers.yaml]
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2026-06-30 修复mac对moveit的编译
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2026-06-30 mac系统moveit模型与通信修复
    [mockway_description.primitive_collision.urdf, mockway_description.ros2_control.xacro, mockway_description.urdf.xacro]
